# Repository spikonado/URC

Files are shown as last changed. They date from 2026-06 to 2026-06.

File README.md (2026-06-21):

# Universal Robot Controller (URC)

View PCB on KiCanvas (https://kicanvas.org/?github=https://github.com/spikonado/URC/tree/main/pcb_design)

## Graphics

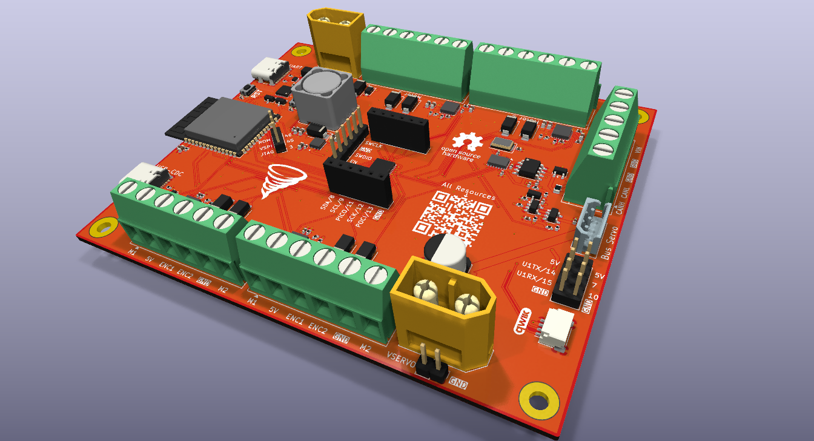
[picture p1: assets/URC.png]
Render


## Features

This is what the board can do:

- Can precisely control up to <ins>**4 Brushed DC Motors**</ins> with or without quadrature <ins>**encoders**</ins>.
- Can precisely control <ins>**Serial Bus Servos**</ins> from Feetech, Waveshare, etc.
- Communicate with and control a variety of <ins>**2D LiDARs**</ins>.
- Communicate with and control other robotics hardware through <ins>**CAN FD**</ins>.
- Supports voltages up to <ins>**36V**</ins>.
- Incredible support for <ins>**ROS 2**</ins>.

The board has two microcontrollers:

1. An [ESP32-S3 module](https://documentation.espressif.com/esp32-s3_datasheet_en.pdf), specifically the [ESP32-S3-WROOM-1-N16R8](https://documentation.espressif.com/esp32-s3-wroom-1_wroom-1u_datasheet_en.pdf), which comes with 16 MB flash and 8 MB PSRAM.
2. An [STM32G431KBU6](https://www.st.com/en/microcontrollers-microprocessors/stm32g431kb.html) being used specifically for motor control.

## Why?

There are no robot control boards out there that allow one to make a fully functional robot with just the board and a power source as the electronics.

Before this board existed, to make a robot that has 4 motors, 2 robot arms, and a LiDAR, one would need to buy the following:

1. A development board of a microcontroller like an ESP32.
2. A board that can connect to and control 4 DC Motors with quadrature encoders.
3. A board that can control Serial Bus Servos.
4. An SBC like a Raspberry Pi for the LiDAR.

And even after all of this, it would still be a headache to get all of that working together and using ROS 2 with it.

## Using the Board

1. Connect a USB-C cable to one of the board's USB-C ports.
2. If using the USB-CDC port, make sure to enable USB-CDC in Arduino IDE before trying to upload the firmware.
3. Flash one of the [firmware examples](./firmware_examples/).
4. Connect the board to the the peripherals you are using according to the wiring guide in the firmware examples.

## Zine

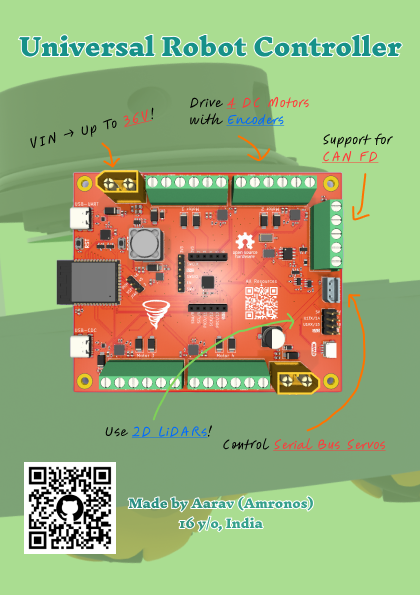
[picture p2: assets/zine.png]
Zine


## BOM

| Reference | Qty | Value / Part | Footprint | Manufacturer | MPN | Unit Price ($) | Total Price ($) |
| --- | --- | --- | --- | --- | --- | --- | --- |
| C1,C3,C5,C6,C14,C15,C17,C18,C38 | 9 | 10µF, 16V | C_0603_1608Metric | Murata Electronics | GRT188R61C106KE13D | 0.447 | 4.023 |
| C2,C4,C7,C8,C9,C13,C16,C19,C20,C29,C32,C33,C37,C63,C64,C65 | 16  | 100nF, 16V | C_0402_1005Metric | Samsung Electro-Mechanics | CL05B104KO5NNNC | 0.025 | 0.400 |
| C10,C11 | 2 | 4.7µF, 50V | C_0805_2012Metric | Murata Electronics | GRT21BR61H475KE13L | 0.940 | 1.880 |
| C12,C23,C26,C36,C41,C47,C53,C59 | 8 | 100nF, 50V | C_0402_1005Metric | Murata Electronics | GRM155R61H104KE14D | 0.120 | 0.960 |
| C21,C22,C24,C25,C34,C35,C42,C43,C45,C46,C51,C52,C57,C58 | 14  | 10µF, 50V | C_0805_2012Metric | Murata Electronics | GRM21BR61H106KE43L | 0.608 | 8.512 |
| C27 | 1 | 470pF, 50V | C_0402_1005Metric | YAGEO | CC0402KRX7R9BB471 | 0.304 | 0.304 |
| C28 | 1 | 100µF | CP_Elec_8x6.9 | KEMET | A768KE107M1VLAS036 | 2.375 | 2.375 |
| C30,C31 | 2 | 10pF, 1% | C_0402_1005Metric | Murata Electronics | GRT1555C1H100FA02D | 0.245 | 0.490 |
| C39,C48,C54,C60 | 4 | 22nF, 50V | C_0402_1005Metric | Murata Electronics | GRM155R71H223JA12D | 0.235 | 0.940 |
| C40,C49,C55,C61 | 4 | 220nF, 16V | C_0603_1608Metric | Samsung Electro-Mechanics | CL10B224KO8NNNC | 0.251 | 1.004 |
| C44,C50,C56,C62 | 4 | 470nF, 10V | C_0402_1005Metric | Murata Electronics | GRM155R71A474KE01D | 0.319 | 1.276 |
| D1,D2,D3,D5,D7,D8,D9,D10,D11,D12,D13,D14,D16 | 13  | SS14 | D_SMA | onsemi | SS14 | 0.189 | 2.457 |
| D6 | 1 | D_TVS_Dual_AAC | SOT-23-3 | onsemi | NUP2105LT1G | 0.403 | 0.403 |
| J1,J2 | 2 | USB-C Receptacle USB2.0 16P | USB4105-xx-A 16P  | GCT | USB4105-GF-A | 1.251 | 2.502 |
| J3,J6 | 2 | XT60-M | XT60 Vertical | Changzhou Amass Elec | XT60-M | 0.906 | 1.812 |
| J7 | 1 | 5267-03A | Molex SPOX 3-pin  | Molex | 22-03-5035 | 0.564 | 0.564 |
| J8 | 1 | Screw Terminal 1x05 | TB007-508-05 | Same Sky | TB007-508-05BE | 2.330 | 2.330 |
| J10,J11,J12,J13 | 4 | Screw Terminal 1x06 | TB007-508-06 | Same Sky | TB007-508-06BE | 2.736 | 10.944 |
| J15 | 1 | JST SH 4-pin | SM04B-SRSS-TB | JST | SM04B-SRSS-TB | 2.013 | 2.013 |
| L1 | 1 | 3.3µH | SRR1210A | Bourns | SRR1210-3R3Y | 2.278 | 2.278 |
| Q1,Q2 | 2 | MMBT3904 | SOT-23 | onsemi | MMBT3904LT1G | 0.509 | 1.018 |
| Q3 | 1 | MMBT3906 | SOT-23 | onsemi | MMBT3906LT1G | 1.198 | 1.198 |
| R1,R2,R3,R4 | 4 | 5.1kΩ, 0.1% | R_0402_1005Metric | Panasonic | ERA-2AEB512X | 0.473 | 1.892 |
| R5 | 1 | 1kΩ, 5% | R_0402_1005Metric | YAGEO | RC0402JR-071KL | 0.132 | 0.132 |
| R6 | 1 | 22.1kΩ, 1% | R_0402_1005Metric | Panasonic | ERJ-2RKF2212X | 0.485 | 0.485 |
| R7 | 1 | 47.5kΩ, 1% | R_0402_1005Metric | YAGEO | RC0402FR-0747K5L | 0.123 | 0.123 |
| R8,R11,R12,R15,R17,R19,R20,R23,R24,R26,R27,R29,R30,R31 | 14  | 10kΩ, 5% | R_0402_1005Metric | YAGEO | RC0402JR-0710KL | 0.015 | 0.210 |
| R9 | 1 | 100kΩ, 0.1% | R_0402_1005Metric | YAGEO | RT0402BRE07100KL | 1.542 | 1.542 |
| R10 | 1 | 19.1kΩ, 0.1% | R_0402_1005Metric | YAGEO | RT0402BRD0719K1L | 1.475 | 1.475 |
| R13 | 1 | 20kΩ, 5% | R_0402_1005Metric | YAGEO | RC0402JR-0720KL | 0.108 | 0.108 |
| R14,R16 | 2 | 100Ω, 5% | R_0402_1005Metric | Panasonic | ERJ-PA2J101X | 1.455 | 2.910 |
| R18 | 1 | 120Ω, 5% | R_0805_2012Metric | Panasonic | ERJ-UP6F1200V | 0.220 | 0.220 |
| R21,R22,R25,R28 | 4 | 330kΩ, 5% | R_0402_1005Metric | YAGEO | RC0402FR-07330KL | 0.032 | 0.128 |
| SW1,SW2 | 2 | Push Button | KMR2 | C&K | KMR223G LFG | 1.811 | 3.622 |
| U1,U2 | 2 | USBLC6-2P6 | SOT-666 | STMicroelectronics | USBLC6-2P6 | 0.720 | 1.440 |
| U3 | 1 | CP2102N USB-UART | QFN-24 | Silicon Labs | CP2102N-A02-GQFN24 | 4.025 | 4.025 |
| U4 | 1 | ESP32-S3-WROOM-1-N16R8 | ESP32-S3-WROOM-1  | Espressif Systems | ESP32-S3-WROOM-1-N16R8 | 4.830 | 4.830 |
| U5 | 1 | LMR51635YDDCR | TSOT-23-6 | Texas Instruments | LMR51635YDDCR | 3.220 | 3.220 |
| U6 | 1 | LD39200PU33R | LD39200PU33R | STMicroelectronics | LD39200PU33R | 1.302 | 1.302 |
| U7 | 1 | SN74LVC1G125DBVR | SOT-23-5 | Texas Instruments | SN74LVC1G125DBVR | 0.604 | 0.604 |
| U8 | 1 | SN74LVC1G126DBVR | SOT-23-5 | Texas Instruments | SN74LVC1G126DBVR | 0.973 | 0.973 |
| U9 | 1 | MCP2518FD CAN-FD Controller | DFN-14 | Microchip Technology | MCP2518FDT-E/QBB | 2.278 | 2.278 |
| U10 | 1 | MCP2562 CAN Transceiver | SOIC-8 | Microchip Technology | MCP2562-E/SN | 1.775 | 1.775 |
| U11 | 1 | STM32G431KBU6 | QFN-32 | STMicroelectronics | STM32G431KBU6 | 5.110 | 5.110 |
| U12,U13,U14,U15 | 4 | DRV8256PRGER | VQFN-24 | Texas Instruments | DRV8256PRGER | 2.467 | 9.868 |
| Y1 | 1 | 40 MHz Crystal | 5032 SMD | SUZHOU HANGJING ELEC&TECH CO., LTD | 0153G2-40.000F18HPLJK | 2.800 | 2.800 |
| **Full PCB Manufacturing** | 1 | | | | | ~150 | ~150 |
| **ST-Link/V2** | 1 | | | | https://www.prayogindia.in/product/st-link-v2-in-circuit-debugger-programmer-for-stm8-and-stm32 | ~15 | ~15 |
| **Grand Total** | | | | | | | **~165** |

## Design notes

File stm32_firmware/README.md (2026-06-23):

## Flashing the STM32

Run the following commands after installing `west` or sourcing the nix flake:

```bash
west init
west config manifest.path manifest
west update
west build urc_stm32_firmware --board=nucleo_g431kb
```

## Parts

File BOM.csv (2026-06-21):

Reference | Qty | Value | Footprint | Datasheet | Manufacturer | MPN | Unit Price ($) | Total Price ($)
C1,C3,C5,C6,C14,C15,C17,C18,C38 | 9 | 10µF, 16V | Capacitor_SMD:C_0603_1608Metric | https://search.murata.co.jp/Ceramy/image/img/A01X/G101/ENG/GRT188R61C106KE13-01.pdf | Murata Electronics | GRT188R61C106KE13D | 0.447 | 4.023
C2,C4,C7,C8,C9,C13,C16,C19,C20,C29,C32,C33,C37,C63,C64,C65 | 16 | 100nF, 16V | Capacitor_SMD:C_0402_1005Metric | https://weblib.samsungsem.com/mlcc/mlcc-ec-data-sheet.do?partNumber=CL05B104KO5NNN | Samsung Electro-Mechanics | CL05B104KO5NNNC | 0.025 | 0.4
C10,C11 | 2 | 4.7µF, 50V | Capacitor_SMD:C_0805_2012Metric | https://search.murata.co.jp/Ceramy/image/img/A01X/G101/ENG/GRT21BR61H475KE13-01.pdf | Murata Electronics | GRT21BR61H475KE13L | 0.94 | 1.88
C12,C23,C26,C36,C41,C47,C53,C59 | 8 | 100nF, 50V | Capacitor_SMD:C_0402_1005Metric | https://search.murata.co.jp/Ceramy/image/img/A01X/G101/ENG/GRM155R61H104KE14-01.pdf | Murata Electronics | GRM155R61H104KE14D | 0.12 | 0.96
C21,C22,C24,C25,C34,C35,C42,C43,C45,C46,C51,C52,C57,C58 | 14 | 10µF, 50V | Capacitor_SMD:C_0805_2012Metric | https://search.murata.co.jp/Ceramy/image/img/A01X/G101/ENG/GRM21BR61H106KE43-01A.pdf | Murata Electronics | GRM21BR61H106KE43L | 0.608 | 8.512
C27 | 1 | 470pF, 50V | Capacitor_SMD:C_0402_1005Metric | https://yageogroup.com/content/datasheet/asset/file/UPY-GPHC_X7R_6_3V-TO-250V | YAGEO | CC0402KRX7R9BB471 | 0.304 | 0.304
C28 | 1 | 100µF | Capacitor_SMD:CP_Elec_8x6.9 | https://yageogroup.com/content/datasheet/asset/file/KEM_A4088_A768 | KEMET | A768KE107M1VLAS036 | 2.375 | 2.375
C30,C31 | 2 | 10pF, 1% | Capacitor_SMD:C_0402_1005Metric | https://search.murata.co.jp/Ceramy/image/img/A01X/G101/ENG/GRT1555C1H100FA02-01.pdf | Murata Electronics | GRT1555C1H100FA02D | 0.245 | 0.49
C39,C48,C54,C60 | 4 | 22nF, 50V | Capacitor_SMD:C_0402_1005Metric | https://search.murata.co.jp/Ceramy/image/img/A01X/G101/ENG/GRM155R71H223JA12-01A.pdf | Murata Electronics | GRM155R71H223JA12D | 0.235 | 0.94
C40,C49,C55,C61 | 4 | 220nF, 16V | Capacitor_SMD:C_0603_1608Metric | https://mm.digikey.com/Volume0/opasdata/d220001/medias/docus/920/CL10B224KO8NNNC_Spec.pdf | Samsung Electro-Mechanics | CL10B224KO8NNNC | 0.251 | 1.004
C44,C50,C56,C62 | 4 | 470nF, 10V | Capacitor_SMD:C_0402_1005Metric | https://search.murata.co.jp/Ceramy/image/img/A01X/G101/ENG/GRM155R71A474KE01-01.pdf | Murata Electronics | GRM155R71A474KE01D | 0.319 | 1.276
D1,D2,D3,D5,D7,D8,D9,D10,D11,D12,D13,D14,D16 | 13 | SS14 | Diode_SMD:D_SMA | https://www.onsemi.com/pdf/datasheet/ss19-d.pdf | onsemi | SS14 | 0.189 | 2.457
D6 | 1 | D_TVS_Dual_AAC | Package_TO_SOT_SMD:SOT-23-3 | https://www.onsemi.com/pdf/datasheet/nup2105l-d.pdf | onsemi | NUP2105LT1G | 0.403 | 0.403
J1,J2 | 2 | USB_C_Receptacle_USB2.0_16P | Connector_USB:USB_C_Receptacle_GCT_USB4105-xx-A_16P_TopMnt_Horizontal | https://gct.co/files/specs/usb4105-spec.pdf | GCT | USB4105-GF-A | 1.251 | 2.502
J3,J6 | 2 | Conn_01x02_Socket | Connector_AMASS:AMASS_XT60-M_1x02_P7.20mm_Vertical |  | Changzhou Amass Elec | XT60-M | 0.906 | 1.812
J7 | 1 | 5267-03A | Connector_Molex:Molex_SPOX_5267-03A_1x03_P2.50mm_Vertical | https://www.molex.com/en-us/products/part-detail-pdf/22035035?display=pdf | Molex | 22-03-5035 | 0.564 | 0.564
J8 | 1 | Screw_Terminal_01x05 | TerminalBlock_CUI:TerminalBlock_CUI_TB007-508-05_1x05_P5.08mm_Horizontal | https://www.sameskydevices.com/product/resource/tb007-508.pdf | Same Sky | TB007-508-05BE | 2.33 | 2.33
J10,J11,J12,J13 | 4 | Screw_Terminal_01x06 | TerminalBlock_CUI:TerminalBlock_CUI_TB007-508-06_1x06_P5.08mm_Horizontal | https://www.sameskydevices.com/product/resource/tb007-508.pdf | Same Sky | TB007-508-06BE | 2.736 | 10.944
J15 | 1 | Conn_01x04_MountingPin | Connector_JST:JST_SH_SM04B-SRSS-TB_1x04-1MP_P1.00mm_Horizontal | https://www.jst-mfg.com/product/pdf/eng/eSH.pdf | JST | SM04B-SRSS-TB | 2.013 | 2.013
L1 | 1 | 3.3 µH | Inductor_SMD:L_Bourns_SRR1210A | https://www.bourns.com/docs/Product-Datasheets/SRR1210.pdf | Bourns | SRR1210-3R3Y | 2.278 | 2.278
Q1,Q2 | 2 | MMBT3904 | Package_TO_SOT_SMD:SOT-23 | https://www.onsemi.com/pdf/datasheet/pzt3904-d.pdf | onsemi | MMBT3904LT1G | 0.509 | 1.018
Q3 | 1 | MMBT3906LT1G | Package_TO_SOT_SMD:SOT-23 | https://www.onsemi.com/pdf/datasheet/mmbt3906lt1-d.pdf | onsemi | MMBT3906LT1G | 1.198 | 1.198
R1,R2,R3,R4 | 4 | 5.1 kΩ, 0.1% | Resistor_SMD:R_0402_1005Metric | https://industrial.panasonic.com/cdbs/www-data/pdf/RDM0000/AOA0000C307.pdf | Panasonic | ERA-2AEB512X | 0.473 | 1.892
R5 | 1 | 1 kΩ, 5% | Capacitor_SMD:C_0402_1005Metric | https://yageogroup.com/content/datasheet/asset/file/PYU-RC_GROUP_51_ROHS_L | YAGEO | RC0402JR-071KL | 0.132 | 0.132
R6 | 1 | 22.1 kΩ, 1% | Capacitor_SMD:C_0402_1005Metric | https://industrial.panasonic.com/cdbs/www-data/pdf/RDA0000/AOA0000C304.pdf | Panasonic | ERJ-2RKF2212X | 0.485 | 0.485
R7 | 1 | 47.5 kΩ, 1% | Capacitor_SMD:C_0402_1005Metric | https://yageogroup.com/content/datasheet/asset/file/PYU-RC_GROUP_51_ROHS_L | YAGEO | RC0402FR-0747K5L | 0.123 | 0.123
R8,R11,R12,R15,R17,R19,R20,R23,R24,R26,R27,R29,R30,R31 | 14 | 10kΩ, 5% | Resistor_SMD:R_0402_1005Metric | https://yageogroup.com/content/datasheet/asset/file/PYU-RC_GROUP_51_ROHS_L | YAGEO | RC0402JR-0710KL | 0.015 | 0.21
R9 | 1 | 100kΩ, 0.1% | Capacitor_SMD:C_0402_1005Metric | https://yageogroup.com/content/datasheet/asset/file/PYU-RT_1-TO-0-01_ROHS_L | YAGEO | RT0402BRE07100KL | 1.542 | 1.542
R10 | 1 | 19.1 kΩ, 0.1% | Capacitor_SMD:C_0402_1005Metric | https://yageogroup.com/content/datasheet/asset/file/PYU-RT_1-TO-0-01_ROHS_L | YAGEO | RT0402BRD0719K1L | 1.475 | 1.475
R13 | 1 | 20kΩ, 5% | Resistor_SMD:R_0402_1005Metric | https://yageogroup.com/content/datasheet/asset/file/PYU-RC_GROUP_51_ROHS_L | YAGEO | RC0402JR-0720KL | 0.108 | 0.108
R14,R16 | 2 | 100Ω, 5% | Resistor_SMD:R_0402_1005Metric | https://industrial.panasonic.com/cdbs/www-data/pdf/RDO0000/AOA0000C331.pdf | Panasonic | ERJ-PA2J101X | 1.455 | 2.91
R18 | 1 | 120Ω, 5% | Resistor_SMD:R_0805_2012Metric | https://industrial.panasonic.com/cdbs/www-data/pdf/RDP0000/AOA0000C337.pdf | Panasonic | ERJ-UP6F1200V | 0.22 | 0.22
R21,R22,R25,R28 | 4 | 330kΩ, 5% | Resistor_SMD:R_0402_1005Metric | https://yageogroup.com/content/datasheet/asset/file/PYU-RC_GROUP_51_ROHS_L | YAGEO | RC0402FR-07330KL | 0.032 | 0.128
SW1,SW2 | 2 | SW_Push | Button_Switch_SMD:SW_Push_1P1T_NO_CK_KMR2 | http://www.ckswitches.com/media/1479/kmr2.pdf | C&K | KMR223G LFG | 1.811 | 3.622
U1,U2 | 2 | USBLC6-2P6 | Package_TO_SOT_SMD:SOT-666 | https://www.st.com/resource/en/datasheet/usblc6-2.pdf | STMicroelectronics | USBLC6-2P6 | 0.72 | 1.44
U3 | 1 | CP2102N-A02-GQFN24 | Package_DFN_QFN:QFN-24-1EP_4x4mm_P0.5mm_EP2.6x2.6mm_ThermalVias | https://www.silabs.com/documents/public/data-sheets/cp2102n-datasheet.pdf | Silicon Labs | CP2102N-A02-GQFN24 | 4.025 | 4.025
U4 | 1 | ESP32-S3-WROOM-1 | RF_Module:ESP32-S3-WROOM-1 | https://www.espressif.com/sites/default/files/documentation/esp32-s3-wroom-1_wroom-1u_datasheet_en.pdf | Espressif Systems | ESP32-S3-WROOM-1-N16R8 | 4.83 | 4.83
U5 | 1 | LMR51635YDDCR | Package_TO_SOT_SMD:TSOT-23-6 | https://www.ti.com/lit/ds/symlink/lmr51635.pdf | Texas Instruments | LMR51635YDDCR | 3.22 | 3.22
U6 | 1 | LD39200PU33R | URC:LD39200PU33R | https://www.st.com/content/ccc/resource/technical/document/datasheet/4b/e6/2e/a4/16/04/46/9d/DM00102135.pdf/files/DM00102135.pdf/jcr:content/translations/en.D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 | STMicroelectronics | LD39200PU33R | 1.302 | 1.302
U7 | 1 | SN74LVC1G125DBV | Package_TO_SOT_SMD:SOT-23-5 | http://www.ti.com/lit/ds/symlink/sn74lvc1g125.pdf | Texas Instruments | SN74LVC1G125DBVR | 0.604 | 0.604
U8 | 1 | SN74LVC1G126DBV | Package_TO_SOT_SMD:SOT-23-5 | http://www.ti.com/lit/ds/symlink/sn74lvc1g126.pdf | Texas Instruments | SN74LVC1G126DBVR | 0.973 | 0.973
U9 | 1 | MCP2518FD-xQBB | Package_DFN_QFN:DFN-14-1EP_3x4.5mm_P0.65mm_EP1.65x4.25mm_ThermalVias | https://ww1.microchip.com/downloads/aemDocuments/documents/OTH/ProductDocuments/DataSheets/External-CAN-FD-Controller-with-SPI-Interface-DS20006027B.pdf | Microchip Technology | MCP2518FDT-E/QBB | 2.278 | 2.278
U10 | 1 | MCP2562-E-SN | Package_SO:SOIC-8_3.9x4.9mm_P1.27mm | http://ww1.microchip.com/downloads/en/DeviceDoc/25167A.pdf | Microchip Technology | MCP2562-E/SN | 1.775 | 1.775
U11 | 1 | STM32G431KBU6 | Package_DFN_QFN:QFN-32-1EP_5x5mm_P0.5mm_EP3.45x3.45mm_ThermalVias | https://www.st.com/resource/en/datasheet/stm32g431kb.pdf | STMicroelectronics | STM32G431KBU6 | 5.11 | 5.11
U12,U13,U14,U15 | 4 | DRV8256PRGER | Package_DFN_QFN:VQFN-24-1EP_4x4mm_P0.5mm_EP2.5x2.5mm_ThermalVias | https://www.ti.com/lit/ds/symlink/drv8256.pdf | Texas Instruments | DRV8256PRGER | 2.467 | 9.868
Y1 | 1 | 40 MHz | Crystal:Crystal_SMD_5032-2Pin_5.0x3.2mm | https://www.hcixtal.com/uploads/44524/files/0153G2.pdf | SUZHOU HANGJING ELEC&TECH CO., LTD | 0153G2-40.000F18HPLJK | 2.8 | 2.8
 |  |  |  |  |  |  |  | Total Price for PCB Manufacturing: ~150
ST-Link/V2 | 1 |  |  |  | STMicroelectronics | https://www.prayogindia.in/product/st-link-v2-in-circuit-debugger-programmer-for-stm8-and-stm32 | ~15 | ~15
 |  |  |  |  |  |  |  | Total Price: ~165

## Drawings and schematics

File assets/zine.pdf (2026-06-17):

# Universal Robot Controller

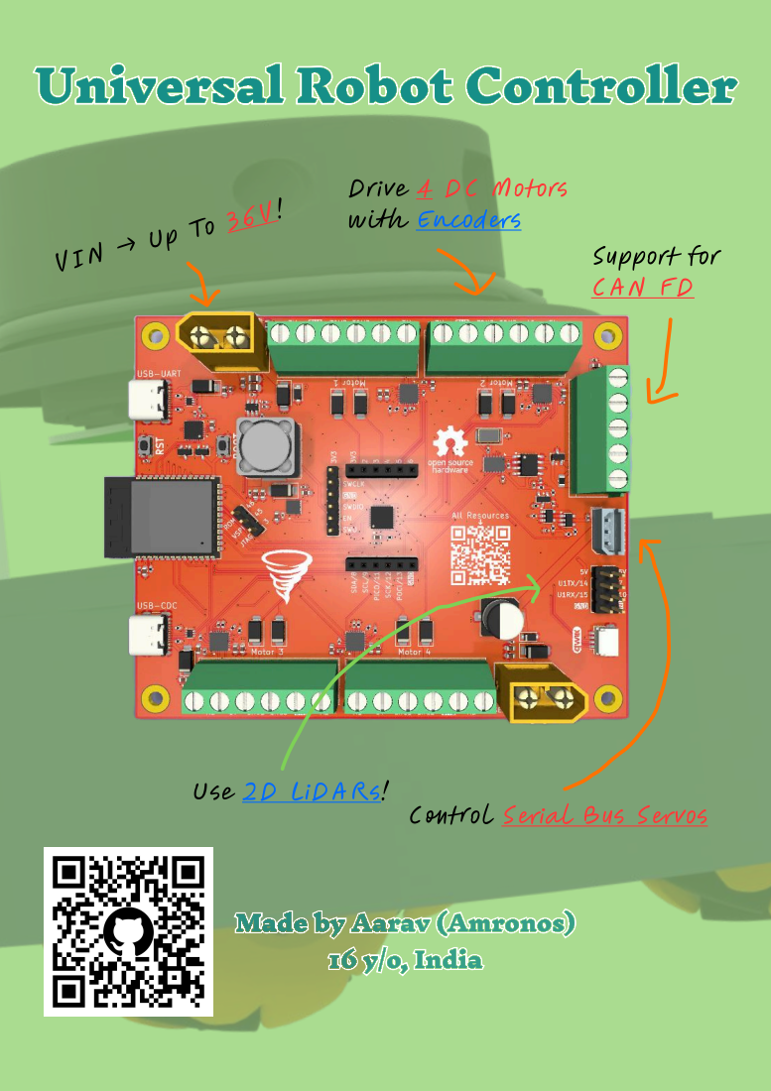
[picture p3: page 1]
withEncoders; Support for CAN FD; Use2D LiDARs!; 16 y/o, India

VIN → Up To 36V! Drive 4 DC Motors

Control Serial Bus Servos

Made by Aarav (Amronos)

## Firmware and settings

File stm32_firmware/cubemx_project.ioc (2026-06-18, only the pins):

Mcu.UserName=STM32G431KBUx
PA0.Signal=GPXTI0
PA1.Signal=GPXTI1
PA10.Signal=S_TIM1_CH3
PA11.Signal=S_TIM1_CH4
PA12.Signal=GPXTI12
PA13.Signal=SYS_JTMS-SWDIO
PA14.Signal=SYS_JTCK-SWCLK
PA15.Signal=S_TIM8_CH1
PA2.Signal=S_TIM2_CH3
PA3.Signal=S_TIM2_CH4
PA4.Signal=SPI1_NSS
PA5.Signal=SPI1_SCK
PA6.Signal=SPI1_MISO
PA7.Signal=SPI1_MOSI
PA8.Signal=GPXTI8
PA9.Signal=GPXTI9
PB0.Signal=S_TIM3_CH3
PB3.Signal=SYS_JTDO-SWO
PB4.Signal=GPXTI4
PB5.Signal=GPXTI5
PB6.Signal=GPXTI6
PB7.Signal=S_TIM3_CH4
PB8-BOOT0.Signal=S_TIM4_CH3
PF1-OSC_OUT.Signal=GPIO_Output

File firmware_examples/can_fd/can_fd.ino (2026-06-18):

/*
 * Wiring Guide: Connect the CAN FD peripheral to the board by wiring the CANH and CANL lines to the CANH and CANL pins on the board.
 */

#include <ACAN2517FD.h>  // Make sure to install the ACAN2517FD Arduino Library
#include <SPI.h>

SPIClass hspi(HSPI);
ACAN2517FD can(38, hspi, 41);

#define LED_PIN 2  // Make sure to attach an LED to this pin

void setup()
{
  pinMode(LED_PIN, OUTPUT);
  digitalWrite(LED_PIN, HIGH);

  Serial.begin(115200);

  hspi.begin(18, 21, 17);

  Serial.print("sizeof (ACAN2517FDSettings): ");
  Serial.print(sizeof(ACAN2517FDSettings));
  Serial.println(" bytes");
  Serial.println("Configure ACAN2517FD");

  ACAN2517FDSettings settings(
    ACAN2517FDSettings::OSC_4MHz10xPLL, 125 * 1000, DataBitRateFactor::x1);
  settings.mRequestedMode = ACAN2517FDSettings::InternalLoopBack;

  Serial.print("MCP2517FD RAM Usage: ");
  Serial.print(settings.ramUsage());
  Serial.println(" bytes");

  const uint32_t errorCode = can.begin(settings, [] { can.isr(); });
  if (errorCode == 0) {
    Serial.print("Bit Rate prescaler: ");
    Serial.println(settings.mBitRatePrescaler);
    Serial.print("Arbitration Phase segment 1: ");
    Serial.println(settings.mArbitrationPhaseSegment1);
    Serial.print("Arbitration Phase segment 2: ");
    Serial.println(settings.mArbitrationPhaseSegment2);
    Serial.print("Arbitration SJW:");
    Serial.println(settings.mArbitrationSJW);
    Serial.print("Actual Arbitration Bit Rate: ");
    Serial.print(settings.actualArbitrationBitRate());
    Serial.println(" bit/s");
    Serial.print("Exact Arbitration Bit Rate ? ");
    Serial.println(settings.exactArbitrationBitRate() ? "yes" : "no");
    Serial.print("Arbitration Sample point: ");
    Serial.print(settings.arbitrationSamplePointFromBitStart());
    Serial.println("%");
  } else {
    Serial.print("Configuration error 0x");
    Serial.println(errorCode, HEX);
  }
}

static uint32_t gBlinkLedDate = 0;
static uint32_t gReceivedFrameCount = 0;
static uint32_t gSentFrameCount = 0;

void loop()
{
  CANFDMessage frame;
  if (gBlinkLedDate < millis()) {
    gBlinkLedDate += 2000;
    digitalWrite(LED_PIN, !digitalRead(LED_PIN));
    const bool ok = can.tryToSend(frame);
    if (ok) {
      gSentFrameCount += 1;
      Serial.print("Sent: ");
      Serial.println(gSentFrameCount);
    } else {
      Serial.println("Send failure");
    }
  }
  if (can.available()) {
    can.receive(frame);
    gReceivedFrameCount++;
    Serial.print("Received: ");
    Serial.println(gReceivedFrameCount);
  }
}

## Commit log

2026-06-16 feat: Initialize repo and create Rev 1.0 of PCB
    [URC.kicad_sch, drivers.kicad_sch, mcu_and_connectors.kicad_sch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]
2026-06-18 feat: Assign functions to all IOs in stm32cubemx
2026-06-18 fix: Update BOM export configuration
    [power_and_usb.kicad_sch, stm32_and_motor_drivers.kicad_sch]
2026-06-18 docs: Add overall BOM
    [BOM.csv]
2026-06-18 feat(firmware): Add some Arduino examples
2026-06-19 fix(PCB): Update MPN and footprint for some passives
    [drivers.kicad_sch, mcu_and_connectors.kicad_sch, stm32_and_motor_drivers.kicad_sch]
2026-06-20 fix(fallout): Add release files to repository
    [BOM.csv]
2026-06-21 feat(pcb): Add more test points
    [mcu_and_connectors.kicad_sch, stm32_and_motor_drivers.kicad_sch]
2026-06-21 fix: Update production files to latest version
    [BOM.csv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]
2026-06-21 feat: Add cost of each component to BOM
    [BOM.csv]
2026-06-22 fix(fallout): Move production files to a new production directory
    [URC-all-pos.csv]
2026-06-23 feat(stm32_firmware): Initialize zephyr project
